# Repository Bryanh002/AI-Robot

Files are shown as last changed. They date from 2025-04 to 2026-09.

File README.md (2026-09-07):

```
███████╗██████╗  ██████╗  ██████╗ ███████╗
██╔════╝██╔══██╗██╔════╝ ██╔═══██╗██╔════╝
█████╗  ██████╔╝██║  ███╗██║   ██║███████╗
██╔══╝  ██╔══██╗██║   ██║██║   ██║╚════██║
███████╗██║  ██║╚██████╔╝╚██████╔╝███████║
╚══════╝╚═╝  ╚═╝ ╚═════╝  ╚═════╝ ╚══════╝
```
### Embodied Reinforcement Gait Optimization System
---

<p align="center">
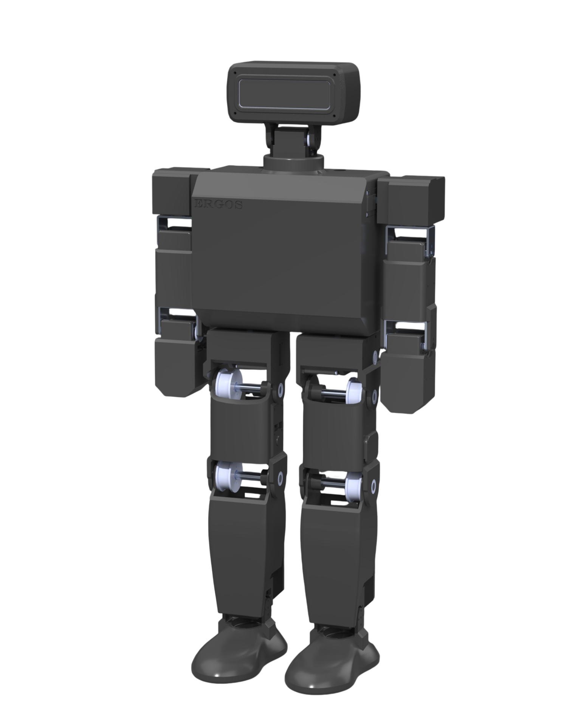
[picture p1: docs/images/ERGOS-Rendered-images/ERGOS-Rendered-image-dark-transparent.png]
  
  <br>
</p>

---

## Project Overview

ERGOS is a low-cost, open-source 20-DOF humanoid platform for dynamic locomotion research. It is a self-contained robot: 3D-printed structure, belt-driven Feetech STS serial servos, a custom motherboard, and a Jetson Orin Nano as the onboard computer.

The long-term goal is stable, adaptive bipedal gait on this hardware. High-level perception, planning, and learned policies run on the Jetson inside a ROS 2 control stack. Low-level servo timing and bus I/O run on an ESP32-S3. Simulation and training use NVIDIA Isaac Sim / Isaac Lab and PyTorch; trained policies are meant to transfer onto the physical robot.

---

## 🗺️ Repository Map

- **Hardware**
  - [`mechanical/`](mechanical/) — SolidWorks CAD (current: ERGOS V1.4), STEP exports, renders, walking tether
  - [`Electrical/`](Electrical/) — Altium motherboard project, schematics, PCB
- **Software**
  - [`software/`](software/) — ESP32 firmware examples now; ROS 2 packages, tools, and simulation wiring as they land
- **Docs**
  - [`docs/`](docs/) — architecture diagram, renders, datasheets, BOM

---

## ERGOS Features

### Mechanical System *(designed — V1.4)*
- Custom 20-DOF humanoid: legs, arms, neck/head, and torso packaging for battery, motherboard, and Jetson
- Belt-driven joints using HTD-3M pulleys (18T driving, 30T driven) for torque amplification at selected axes
- 3D-printed structural housings for low cost and fast iteration
- Modular joint layout so actuators and transmissions can be swapped without redesigning the whole robot
- Safety tether (4040 extrusion frame) for early walking tests

### Electronics & Power *(designed — testing)*
- Custom motherboard with an ESP32-S3 for real-time servo communication
- On-board full-duplex to half-duplex TTL path for two Feetech STS buses at 1 Mbps
- BMI323 IMU on the motherboard; two force-sensing resistors on each foot
- Power from a 3S 8400 mAh LiPo: eFuse-protected distribution to the servo harness, boost to 18 V for the Jetson
- Jetson Orin Nano as the primary compute module; USB from the Jetson powers the PCB logic (ESP32) and carries control
- OAK-D Lite depth camera in the head for later perception work

### Control & Locomotion *(planned)*
- ROS 2 control stack on the Jetson: policy inference, state estimation, and command streaming to the ESP32
- Reinforcement learning for walking, trained in simulation and transferred onto hardware
- Simulation and training in **NVIDIA Isaac Sim / Isaac Lab** with **PyTorch**
- [ServoSim](https://github.com/Bryanh002/ServoSim) research is aimed at getting the best locomotion performance on ERGOS given its limited DOF and serial-bus actuator class

### Environmental Perception *(planned)*
- OAK-D Lite for depth and RGB
- Fusion of vision, IMU, and foot sensing into locomotion and navigation

---

## System Architecture

<p align="center">
  
  <br>
</p>

**Figure 1.** High-level system architecture of the ERGOS humanoid platform. A 3S LiPo feeds the custom motherboard: servo-bus power at battery voltage, and a boost converter to 18 V for the Jetson Orin Nano (18 V leaves more buffer on the Jetson input). The Jetson runs perception, planning, and learned policies in ROS 2, and powers the ESP32 logic rail over USB while streaming commands. The MCU drives two half-duplex Feetech STS buses and reads the on-board IMU and foot FSRs (two per foot). Arms are 4 DOF each; legs 5 DOF; neck 2 DOF. The OAK-D Lite connects to the Jetson over USB 3.0. Diagram source: [`docs/ergos_mermaidchart.txt`](docs/ergos_mermaidchart.txt).

---

## Development Plan

| Phase | Focus | Status |
| :--- | :--- | :--- |
| **1. Hardware platform** | V1.4 CAD, motherboard (designed — testing), harness, assembly, tether | In progress |
| **2. Embedded control** | ESP32 servo firmware, Jetson bring-up, ROS 2 driver | Starting (bus examples exist) |
| **3. Simulation & RL** | Isaac Sim / Isaac Lab, PyTorch locomotion policies | Planned |
| **4. Sim-to-real walking** | Transfer onto ERGOS, tethered then free walking | Planned |
| **5. Perception** | OAK-D in the control loop | Planned |

**Phase 1 — Hardware platform.** Current work. Build the V1.4 mechanical design. The custom motherboard is designed and in testing (servo buses, power distribution, IMU, foot FSRs, Jetson 18 V rail). Assemble the robot and the walking tether.

**Phase 2 — Embedded control.** Firmware on the ESP32-S3 for dual-bus STS command/feedback, then a ROS 2 layer on the Orin Nano that talks to that MCU. Servo ID map, calibration, and a first standing / joint-tracking controller.

**Phase 3 — Simulation and RL.** Model ERGOS in Isaac Sim / Isaac Lab and train walking policies with PyTorch. This is also where ERGOS is used as the hardware test platform for [ServoSim](https://github.com/Bryanh002/ServoSim).

**Phase 4 — Sim-to-real walking.** Run trained policies on the Jetson, first on the tether, then untethered.

**Phase 5 — Perception.** Bring the OAK-D Lite into locomotion and navigation.

---

## Technical Summary

| Item | Choice |
| :--- | :--- |
| **On-robot compute** | NVIDIA Jetson Orin Nano (JetPack, ROS 2) |
| **Real-time MCU** | ESP32-S3 (C/C++, Arduino today) |
| **Actuators** | Feetech STS3250 (14×) and STS3235 (6×), TTL half-duplex @ 1 Mbps |
| **Sensors** | BMI323 IMU, OAK-D Lite, two FSRs per foot |
| **Power** | 3S 8400 mAh LiPo → motherboard eFuse / boost (18 V Jetson) / servo rails; Jetson USB powers PCB logic |
| **Simulation & training** | NVIDIA Isaac Sim / Isaac Lab, PyTorch |
| **Control stack** | ROS 2 on the Jetson, USB/UART to the ESP32 |
| **CAD / PCB** | SolidWorks, Altium Designer |

---

## Getting Started

The robot is still being built. There is not a one-command install yet. Use the folders that actually exist:

1. **Mechanical** — [mechanical/README.md](mechanical/README.md) · CAD in `mechanical/ERGOS_V1.4/`, STEP exports, interactive renders. Full assembly instructions will live there; they are not written yet.
2. **Electrical** — [Electrical/README.md](Electrical/README.md) · Altium project, schematic PDF, motherboard overview.
3. **BOM** — [docs/README.md](docs/README.md) · current parts list. This spreadsheet is out of date and will be rebuilt last.
4. **Software** — [software/README.md](software/README.md) · ESP32 bus examples now. ROS 2, Isaac, and training docs come with Phase 2–3.

**Later (when those phases land):** JetPack / Python environment, simulation setup, training and deployment, and a servo ID / wiring map.

---

## 📜 License

This project is open source and released under the **MIT License**.  
See the [LICENSE](LICENSE) file for more information.

---

## 👤 Project Developer

**Bryan Heddle**  
Mechatronics & AI Systems Engineering Student — *Western University*

---

## 💡 Acknowledgments

Thanks to the open-source robotics community for the tools, documentation, and work this project builds on.

**Project sponsors:**
- **[Thompson Innovation Fund](https://www.eng.uwo.ca/tc/innovation-fund.html)**
- **[WESEF](https://www.eng.uwo.ca/departments-units/finance-stores/undergrads/wesef.html)**
- **[Luxonis](https://www.luxonis.com/)**
- **[GoBilda](https://www.gobilda.com/)**
---

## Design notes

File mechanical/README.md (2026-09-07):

# Mechanical

ERGOS V1.4 is the current mechanical design: a 20-DOF 3D-printed humanoid with belt-driven joints and Feetech STS serial servos.

This page is a map of the CAD, not a full assembly manual. That manual will live here when the build is stable enough to write down.

## What's in this folder

| Path | Contents |
| :--- | :--- |
| [`ERGOS_V1.4/`](ERGOS_V1.4/) | Current robot — parts, assemblies, STEP exports |
| [`ERGOS_Tether_V2/`](ERGOS_Tether_V2/) | Walking-support frame (4040 extrusion, casters) |
| [`ERGOS_Tether_V1/`](ERGOS_Tether_V1/) | Earlier tether |
| [`Renders/`](Renders/) | Interactive 360° viewers and stills |
| [`Prototypes [Legacy]/`](Prototypes%20[Legacy]/) | V1–V1.3 CAD kept for history |

Open **`ERGOS_V1.4/Assemblies/Final_Robot_Assembly.SLDASM`** for the full robot.

## Design snapshot (V1.4)

- **Structure:** printed housings (PLA for most structure; TPU where compliance is needed) with COTS bearings, shafts, and fasteners
- **Actuation:** Feetech STS3250 on the high-load joints (hips, knees, shoulders) and STS3235 on lighter joints (arms, neck)
- **Transmission:** selected joints use HTD-3M belts — 18T pulley on the servo side, 30T on the output — for torque at the expense of speed
- **Packaging:** battery, motherboard, and Jetson Orin Nano in the torso; OAK-D Lite in the head behind the visor
- **Support:** a 4040 tether so early walking tests do not dump the robot on the floor

Datasheets for the servos are in [`docs/Datasheets/`](../docs/Datasheets/).

## CAD layout (V1.4)

```
ERGOS_V1.4/
  Assemblies/     top-level and subsystem assemblies
  Parts/          printed parts + COTS models used in those assemblies
  Exports/        STEP for print / fab / sharing
```

### Top-level assemblies

| Assembly | Role |
| :--- | :--- |
| `Final_Robot_Assembly.SLDASM` | Full robot |
| `Chassis_Assembly.SLDASM` | Torso, battery, PCB tray, Jetson |
| `Robot_Head_Assembly.SLDASM` | Head, visor, OAK-D Lite, neck |
| `Shoulder_Assembly_Left/Right.SLDASM` | Shoulders |
| `Upper_Arm_Assembly.SLDASM` / `Lower_Arm_Assembly.SLDASM` | Arms |
| `Hip_Housing_Assembly_Left/Right.SLDASM` | Hips |
| `Thigh_Housing_Assembly_Left/Right.SLDASM` | Thighs |
| `Shin_Left/Right_Assembly.SLDASM` | Shins |
| `Ankle_Assembly_Left/Right.SLDASM` | Ankles / feet |
| `Jetson_Orin_Nano_Assembly.SLDASM` | Orin Nano + mounter |
| `ROBOT_MOTHERBOARD.SLDASM` | Motherboard STEP in CAD |
| `Oak-d-lite.SLDASM` | Camera |

Left/right copies of housings are explicit parts (not a single mirrored configuration), so print the matching file for each side.

### Joints and hardware that show up often

- **Pulleys:** `HTD3M-18T-8mm`, `HTD3M-30T-10mm`
- **Shafts:** 8 mm aluminum, several cut lengths (about 30 mm and 68 mm in CAD)
- **Bearings:** MR148 and 6801-2RS at different joints
- **Servo interface:** 25T spline horns (`Servo-horn-gear`, `Servo-horn-smooth`) and GoBilda 8 mm round servo shafts where the belt stage needs a round shaft
- **Shims:** 8×11×0.25 mm washers

A print list, belt lengths, and fastener callouts will go here when the BOM is rebuilt. Do not treat [`docs/README.md`](../docs/README.md) as exact quantities until that happens.

## Tether

`ERGOS_Tether_V2/` is a rolling 4040 frame with casters so the robot can walk with catch support. Use this for Phase 4 (sim-to-real walking) before untethered tests.

## Renders

Current SolidWorks visualizer export. Open [`Renders/ERGOS-Interactive/Data/index.html`](Renders/ERGOS-Interactive/Data/index.html) locally and drag to rotate.

<p align="center">
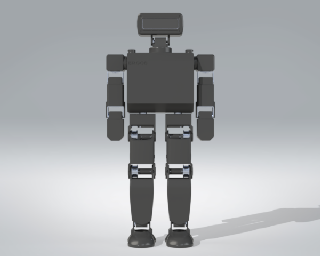
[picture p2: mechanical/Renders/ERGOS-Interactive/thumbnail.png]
ERGOS interactive CAD turntable
  
</p>

Still images used on the GitHub README: [`docs/images/ERGOS-Rendered-images/`](../docs/images/ERGOS-Rendered-images/).

## Still to document

- Exploded assembly order (this is the hard one — it will be its own section)
- Print settings, material per part, and support strategy
- Belt routing and tension
- Wiring paths through the limbs into the torso harness
- Mass properties / COM from the SolidWorks assembly

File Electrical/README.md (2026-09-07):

# Electrical

Custom motherboard for ERGOS: servo-bus I/O, power distribution, IMU, foot FSRs, and an 18 V rail for the Jetson Orin Nano.

This is an overview of the current Altium project (V3), not a full bring-up or assembly guide. Schematics and layout are the source of truth.

## What's in this folder

| Path | Contents |
| :--- | :--- |
| [`PCB_Project/ROBOT_PCB_PROJECT.PrjPcb`](PCB_Project/ROBOT_PCB_PROJECT.PrjPcb) | Altium project |
| [`PCB_Project/ROBOT_MOTHERBOARD.PcbDoc`](PCB_Project/ROBOT_MOTHERBOARD.PcbDoc) | Board layout |
| [`PCB_Project/Schematics/`](PCB_Project/Schematics/) | Four schematic sheets + PDF export |
| [`PCB_Project/PCB_BOM.xlsx`](PCB_Project/PCB_BOM.xlsx) | Motherboard component BOM |
| [`images/history/`](images/history/) | V1–V3 board renders |

The robot-level parts list (battery, Jetson, camera, wire, etc.) lives in [`docs/README.md`](../docs/README.md) and will be rebuilt later.

## Board role

The motherboard sits in the torso on the PCB tray. It does four jobs:

1. **Take 3S LiPo power** (nominal 11.1 V) in through an XT90, protect it, and split it.
2. **Feed the servo harness** at battery voltage for the Feetech STS daisy chains.
3. **Boost to 18 V** and send it out a barrel jack to the Jetson Orin Nano Dev Kit. 18 V is used instead of 19 V to leave more buffer on the Jetson input.
4. **Talk to the servos** from an ESP32-S3 over two half-duplex TTL buses, and read the on-board IMU plus foot FSRs.

The Jetson is the high-level computer (ROS 2, camera, policies). The ESP32 is the real-time bus master. They connect over USB: the Jetson both talks to the MCU and **powers the logic side of the PCB** (ESP32 and 3.3 V rail). Servo/power electronics stay on the battery + eFuse path.

## Schematic sheets

| Sheet | What it covers |
| :--- | :--- |
| `MCU_IMU.SchDoc` | ESP32-S3-MINI-1-N8, 3.3 V LDO, USB, boot/reset, BMI323 IMU |
| `UART_LOGIC.SchDoc` | Full-duplex MCU UART → half-duplex STS bus transceivers / buffers (two buses) |
| `Battery_power.SchDoc` | XT90 input, TVS, eFuse, servo-rail distribution and connectors |
| `Jetson_power.SchDoc` | TPS43060 boost 11.1 V → 18 V, barrel-jack output |

A combined PDF is in [`PCB_Project/Schematics/Schematics_PDF.PDF`](PCB_Project/Schematics/Schematics_PDF.PDF).

## Power tree

```
3S LiPo 8400 mAh  (11.1 V nominal)
        │
        ▼
   XT90  →  TVS  →  TPS25985 eFuse
                    │
        ┌───────────┴───────────┐
        ▼                       ▼
  Servo harness (11.1 V)   TPS43060 boost → 18 V barrel jack → Jetson
        │                                              │
        ├─ Neck                                        └─ USB 5V → PCB logic (ESP32)
        ├─ Right arm / right leg
        └─ Left arm / left leg
```

Servo power is not a second regulated 12 V rail; the STS servos run from the 3S pack through the eFuse and harness. The Jetson is fed 18 V on its barrel jack; it then powers the ESP32 side of this board over USB.

There are also keyed fuse holders on the board (`F2`–`F5`) for downstream rails.

## Communication

Two independent **1 Mbps half-duplex Feetech SCS/STS** buses. The MCU UARTs are full duplex; on-board logic (level shifters, inverters, 3-state buffers) turns each into a single-wire TTL servo bus with a direction pin.

Bus split:

- **Bus 1** — neck, right arm, right leg
- **Bus 2** — left arm, left leg

The Jetson talks to the ESP32 over USB (CDC UART) and supplies logic power on that same link. The OAK-D Lite is USB 3.0 into the Jetson, not into this board.

On-board sensors:

- **BMI323** IMU on I²C to the ESP32
- **Foot FSRs** — two per foot, on MCU ADC

## BOM

Motherboard components: [`PCB_Project/PCB_BOM.xlsx`](PCB_Project/PCB_BOM.xlsx)

Robot-level BOM (battery, compute, mechanical, wire): [`docs/README.md`](../docs/README.md) — out of date, rebuild comes last.

## Mechanical fit

CAD for the board is `mechanical/ERGOS_V1.4/Assemblies/ROBOT_MOTHERBOARD.SLDASM` (and the matching `.step`). It mounts in `PCB-tray` in the chassis, with the Jetson on its own mounter above/beside it.

## Firmware on this board

Bring-up sketches that toggle the half-duplex direction pin and talk to an STS servo are in [`software/src/Arduino/Examples/`](../software/README.md). They are not the production firmware.

Servo comms use a project-specific Feetech STS library: **[ERGOS_FTServo_Arduino](https://github.com/Bryanh002/ERGOS_FTServo_Arduino)** — not the stock Feetech `SCServo` package. Same note is in the [software](../software/README.md) docs.

## Board history

Descriptions of what changed between revisions will go here later.

### V1

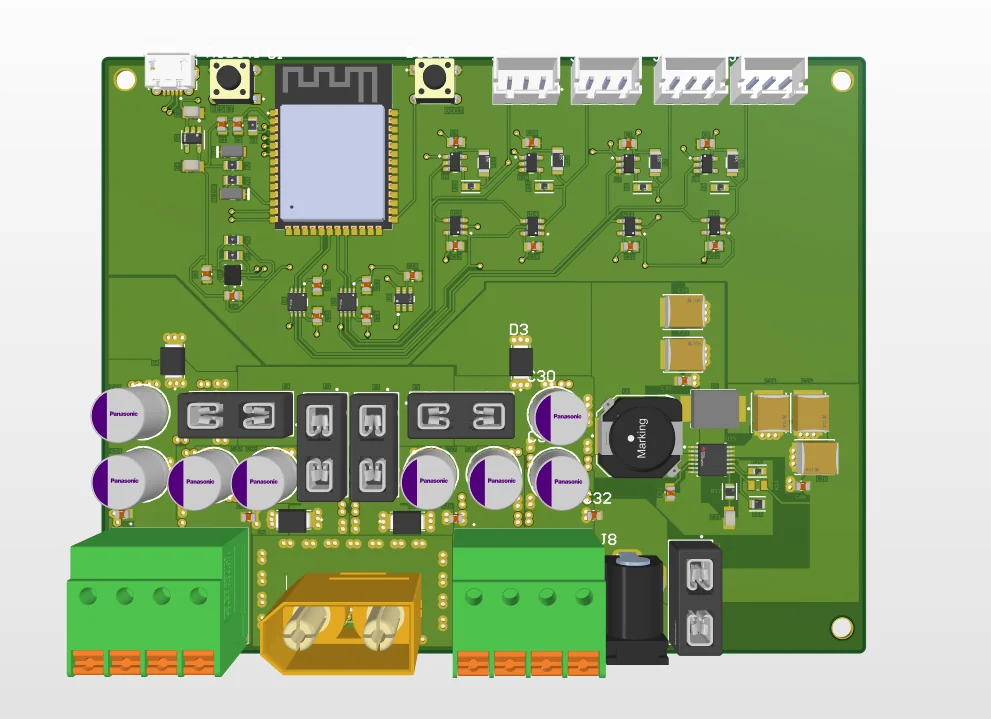
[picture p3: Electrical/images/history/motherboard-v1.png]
ERGOS motherboard V1


### V2

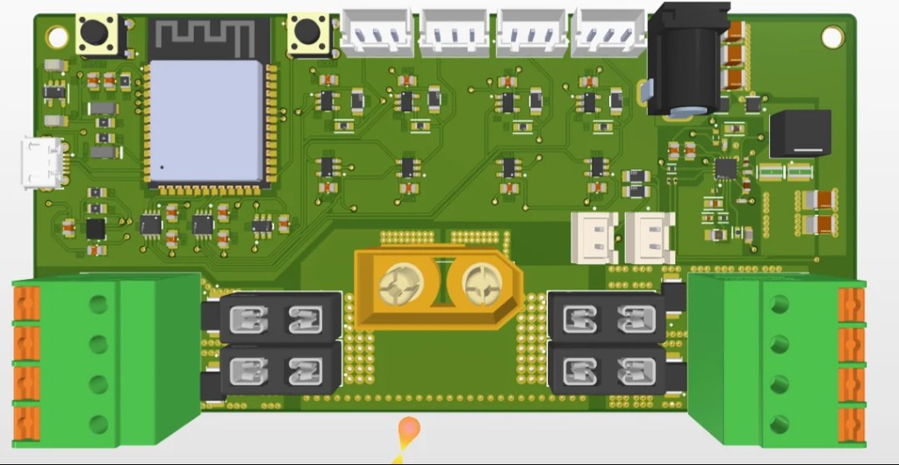
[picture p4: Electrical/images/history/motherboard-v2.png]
ERGOS motherboard V2


### V3 (current)

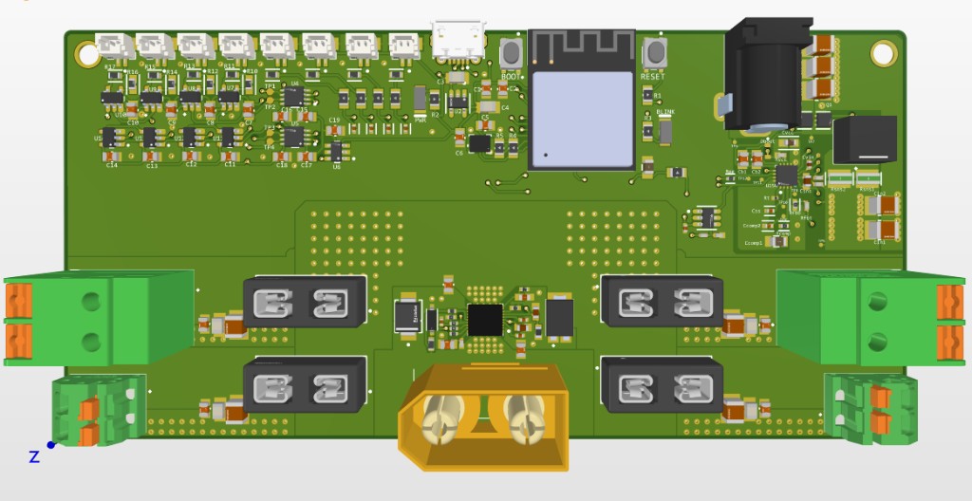
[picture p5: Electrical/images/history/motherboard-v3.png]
ERGOS motherboard V3


## Still to document

- Connector pinouts and harness drawing
- Measured current budgets (idle / walking)
- Programming / boot-button procedure
- First-power checklist

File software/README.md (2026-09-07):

# Software

Software for ERGOS is the stack that will run **on the robot** and the tools used to **train models for it**. That work is still early. This folder currently holds ESP32 bus bring-up sketches only.

ROS 2 packages, Isaac assets, and training code will land here (or be linked from here) as Phase 2–3 start. Until then, treat this page as the intended architecture.

## Intended stack

| Layer | Where it runs | Tools |
| :--- | :--- | :--- |
| Policy training | Workstation / lab GPU | **NVIDIA Isaac Sim**, **Isaac Lab**, **PyTorch** |
| Onboard autonomy | Jetson Orin Nano | **ROS 2**, JetPack, Python / C++ |
| Real-time actuation | ESP32-S3 on the motherboard | C/C++ (Arduino today) |
| Perception | Jetson + OAK-D Lite | DepthAI / ROS 2 camera pipeline *(planned)* |

Flow, once it exists:

1. Train locomotion policies in Isaac Sim / Isaac Lab with PyTorch.
2. Run the policy on the Jetson inside ROS 2 (state in, joint commands out).
3. The Jetson streams commands to the ESP32 over USB/UART and powers the PCB logic rail on that same USB link.
4. The ESP32 is the Feetech STS bus master (two 1 Mbps half-duplex buses) and reads the BMI323 IMU and foot FSRs.

The root README's development plan is the schedule: hardware and MCU bring-up first, then ROS 2, then simulation/RL, then sim-to-real walking.

## ServoSim (separate project)

ERGOS is also the **hardware test platform** for [ServoSim](https://github.com/Bryanh002/ServoSim).

ServoSim is not a substitute for the ERGOS software stack. It is an Isaac Lab extension for learned actuator models and domain randomization on position-controlled serial-bus servos (the same Feetech STS class used here). The research is aimed at getting the best locomotion performance on ERGOS given its limited DOF and actuator class.

- ERGOS software (this repo): robot firmware, ROS 2, the ERGOS sim/control bring-up
- [ServoSim](https://github.com/Bryanh002/ServoSim): servo modeling / DR research that uses ERGOS as the real-world target

## What's in this folder today

```
software/src/Arduino/Examples/
  Full-to-Half_Duplex_Test/   direction-pin toggle on the UART transceiver
  STS_Servo_Ping/             ping / write-position smoke test
  STS_Servo_WritePos/         read position, command two setpoints
```

These sketches talk to a single STS servo on `Serial1` at **1 Mbps**, using **[ERGOS_FTServo_Arduino](https://github.com/Bryanh002/ERGOS_FTServo_Arduino)** — a project-specific Feetech STS library, not the stock `SCServo` package.

| Signal | GPIO (current examples) |
| :--- | :--- |
| UART TX / RX | 12 / 11 (`Serial1`) |
| Bus direction | 4 (HIGH = transmit, LOW = receive) |
| LED | 8 |
| Debug USB serial | 115200 baud |

They match the motherboard's half-duplex direction control. They are not a multi-bus controller, not ROS 2, and not safe to run as a standing robot.

## Planned in this repo (not written yet)

- Production ESP32 firmware: dual bus, ID map, feedback at control rate
- ROS 2 package(s) on the Jetson: MCU bridge, joint states, command interface
- URDF / Isaac description of ERGOS that tracks V1.4 CAD
- Launch files, calibration, and a first standing controller
- Training and deployment notes once the sim model is stable

## Related hardware docs

- [Electrical](../Electrical/README.md) — buses, IMU, FSRs, Jetson 18 V rail
- [Mechanical](../mechanical/README.md) — V1.4 CAD the sim model needs to match
- Servo datasheets: [`docs/Datasheets/`](../docs/Datasheets/)

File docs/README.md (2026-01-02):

# Bill of Materials (BOM)

This folder contains the full Bill of Materials for the project.  
For the original spreadsheet, which contains more detailed descriptions for each part, see [Robot_BOM.xlsx](./Robot_BOM.xlsx).

---

## ⚙️ Mechanical
| Part | Description | Qty | Unit Cost | Total (w/ Tax) |
| :--- | :--- | :---: | :--- | :--- |
| **STS3250 50kg-cm TTL Dual-shaft** | High-torque smart servo for hip, knee, and shoulder joints. | 14 | $65.81 | $1,041.11 |
| **STS3235 30kg-cm TTL Dual-shaft** | Medium-torque smart servo for arm and neck joints. | 6 | $57.86 | $392.29 |
| **8mm Round Servo Shaft** | Shaft adapter for belt-driven joint transmission (15% Discount from GoBilda Applied). | 6 | $9.99 | $67.73 |
| **HTD 3M 18T Timing Pulley** | Driving pulley in belt reduction stage. | 8 | $3.02 | $27.30 |
| **HTD 3M 30T Timing Pulley** | Driven pulley for torque amplification. | 4 | $6.79 | $30.69 |
| **Screw Kit (M1.6–M3)** | Assorted fasteners for structural assembly. | 1 | $11.80 | $13.33 |
| **8mm ID / 11mm OD Washers** | Shim washers to control axial play (15% Discount from GoBilda Applied). | 3 | $2.69 | $9.12 |
| **MR148ZZ Bearings** | Radial bearings for joint rotation. | 1 | $18.95 | $21.41 |
| **Spring Pins** | Mechanical locking pins for shafts. | 1 | $10.19 | $11.51 |
| **TPU Filament** | Flexible filament for compliant parts. | 1 | $29.99 | $33.89 |
| **PLA Filament** | Rigid filament for structural 3D prints. | 3 | $25.99 | $88.11 |
| **Loctite 638** | High-strength retaining compound. | 1 | $24.00 | $27.12 |
| **Mechanical Subtotal** | | | | **$1,763.61** |

---

## ⚡ Electrical
| Part | Description | Qty | Unit Cost | Total (w/ Tax) |
| :--- | :--- | :---: | :--- | :--- |
| **3S LiPo 8400mAh** | Main power source for servos and compute. | 1 | $99.99 | $112.99 |
| **Custom PCB (JLCPCB)** | Power distribution and communication board. | 1 | $283.00 | $319.79 |
| **PCB SMD and THT components** | all components required for PCB. | 1 | $85.00 | $96.05 |
| **Male to Male DC Power Cable** | A power cable for the Jetson that connects to the PCB. | 1 | $10.39 | $11.74 |
| **14 Gauge Wire** | 14 Gauge wire for power distribution | 1 | $22.07 | $24.94 |
| **22 Gauge Wire** | 22 Gauge wire for branching power and signal distribution | 1 | $15.89 | $17.96 |
| **Electrical Subtotal** | | | | **$583.47** |

---

## 🧠 Software & Computing
| Part | Description | Qty | Unit Cost | Total (w/ Tax) |
| :--- | :--- | :---: | :--- | :--- |
| **Jetson Orin Nano** | Main compute for perception, control, and RL. | 1 | $344.95 | $389.79 |
| **OAK-D Lite** | Stereo depth camera for perception (30% Discount from Luxonis applied). | 1 | $162.00 | $183.06 |
| **KingSpec 256GB NVMe SSD** | Storage for models, logs, and datasets. | 1 | $32.99 | $37.28 |
| **Computing Subtotal** | | | | **$610.13** |

---

## 💰 Grand Total
| Category | Total (w/ Tax) |
| :--- | ---: |
| Mechanical | $1,763.61 |
| Electrical | $583.47 |
| Software & Computing | $610.13 |
| **Grand Total** | **$2,957.21** |

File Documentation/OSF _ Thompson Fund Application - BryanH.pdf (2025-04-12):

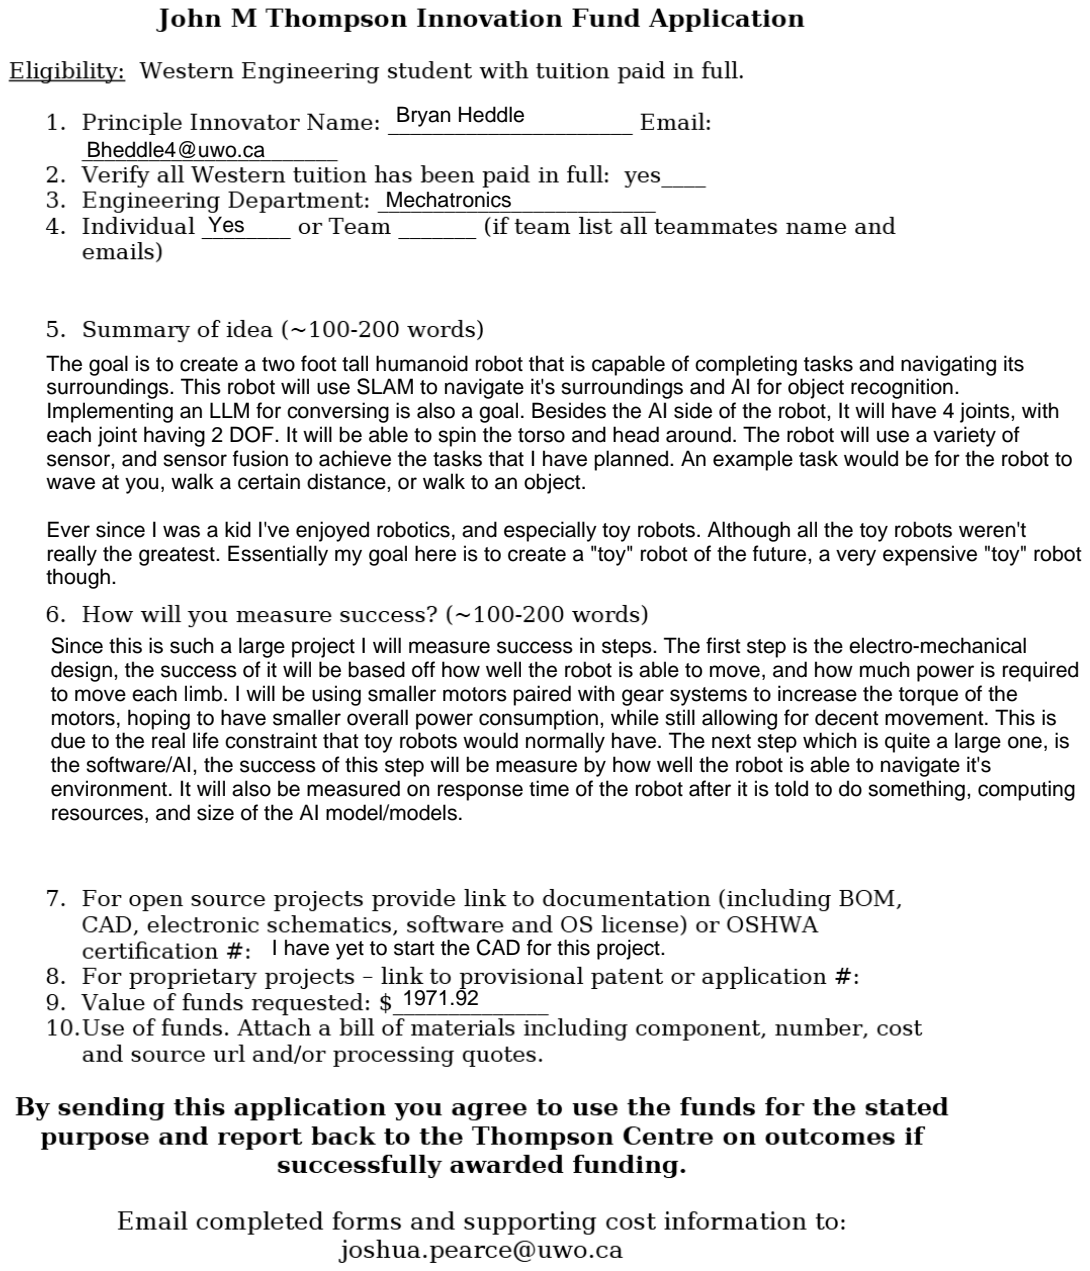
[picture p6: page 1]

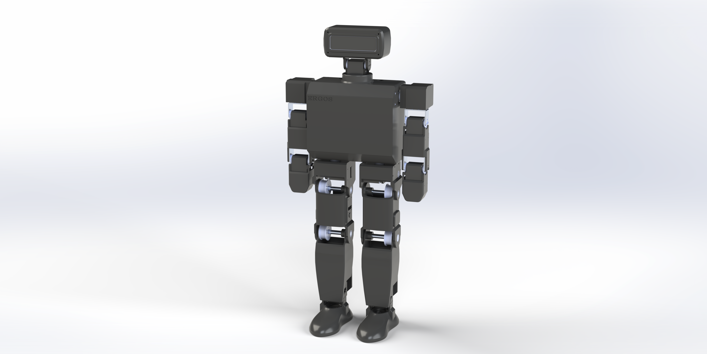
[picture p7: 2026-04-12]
docs/images/ERGOS-Rendered-images/ERGOS-Rendered-image.png

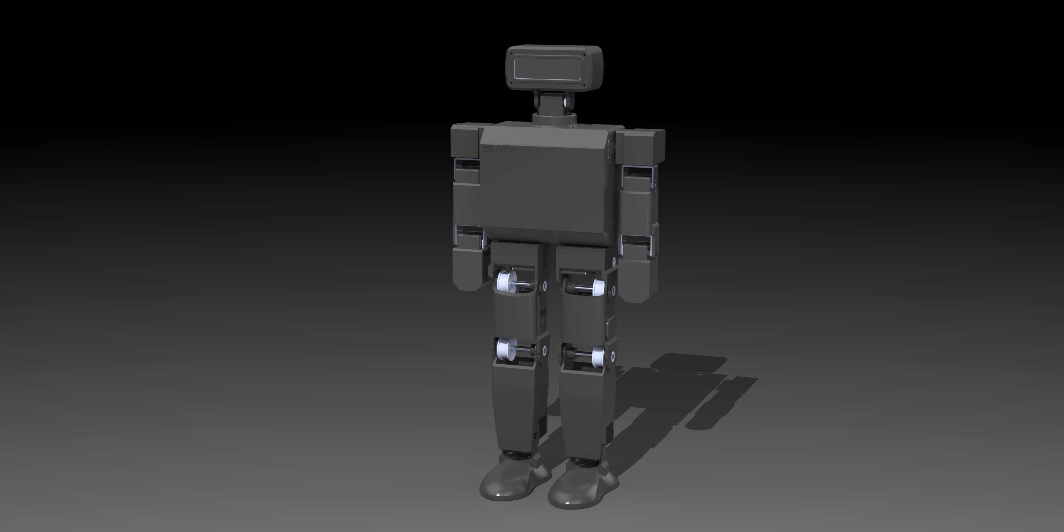
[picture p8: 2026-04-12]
docs/images/ERGOS-Rendered-images/ERGOS-Rendered-image-dark.png

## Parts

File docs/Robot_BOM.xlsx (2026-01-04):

Part | Product Link | Description | Quantity | Cost | Total Cost + Tax | Final Cost
MECHANICAL |  |  |  |  |  | $2876.40
STS3250 50kg-cm TTL Dual-shaft | https://www.feetechrc.com/en/562636.html | High-torque smart servo used for the hip, knee, and shoulder joints to handle the primary load-bearing and dynamic movement required for humanoid locomotion. | 14 | $65.81 | $1041.11
STS3235 30kg-cm TTL Dual-shaft | https://www.feetechrc.com/en/12v-30kg-metal-shell-metal-tooth-iron-core-motor-magnetic-coding-double-shaft-ttl-series-steering-gear.html | Medium-torque smart servo used for arm and neck joints where lower torque is sufficient but precise control is still required for coordinated movement. | 6 | $57.86 | $392.29
8mm Round Servo Shaft | https://www.gobilda.com/8mm-round-servo-shaft-25-tooth-spline-36mm-length/ | Custom shafts used to transfer motion between servo outputs and pulley assemblies, enabling reliable and backlash-free mechanical transmission. | 6 | $9.99 | $67.73
HTD 3M 18T Timing pulley | https://www.aliexpress.com/item/1005007456973949.html | Serves as the driving pulley in the belt transmission system, translating servo rotation. | 8 | $3.02 | $27.30
HTD 3M 30T Timing Pulley | https://www.aliexpress.com/item/1005009686443539.html | Acts as the driven pulley in the gear reduction setup, increasing torque at each joint. | 4 | $6.79 | $30.69
8mm ID 11 mm OD Washers | https://www.gobilda.com/2807-series-stainless-steel-shim-8mm-id-x-11mm-od-0-25mm-thickness-12-pack/ | Used to reduce axial friction and prevent rubbing between rotating parts and stationary brackets. | 1 | $2.69 | $3.04
MR95ZZ Bearings | https://www.amazon.ca/uxcell-Bearings-8x12x3-5mm-Miniature-Precision/dp/B0CM6G9ZKZ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 | Smaller bearings used in compact joint housings where load and speed requirements are moderate. | 1 | $16.29 | $18.41
PLA | https://www.amazon.ca/ELEGOO-Filament-Dimensional-Accuracy-Cardboard/dp/B0C8J1JZMT?s=industrial | 3D printing material used for lightweight housings and custom mounts throughout the robot prototype to allow iterative design, it's likely I'll need lots of PLA due to continous prints, and like mentioned, fixes. | 2 | $44.99 | $101.68
Loctite 638 | https://www.amazon.ca/Loctite-21448-Strength-Retaining-Compound/dp/B000O01EV0 | High-strength retaining compound for securing shafts, pulleys, and bearings, preventing slippage under dynamic loads. | 1 | $24 | $27.12
ELECTRICAL |  |  |  |  | 0
3s lipo 8400mah 11.1v 120c | https://www.amazon.ca/DXF-Battery-Hardcase-Airplane-Helicopter/dp/B09TDFVWHS | Primary power source for servos, Jetson Orin Nano, and sensors; provides sufficient current delivery for high-demand movements. | 1 | $99.99 | $112.99
PCB | JLCPCB | Central power and communication hub distributing regulated voltage and serial signals between servos, Jetson, and sensors. | 1 | $284.00 | $320.92
PCB components | Digikey (https://www.digikey.ca/short/0zvnp1rd) | all components required for PCB | 1 | $109 | $123.17
14 AWG Red and Black Wire |  |  |  |  | 0
SOFTWARE
Jetson Orin Nano | https://www.amazon.ca/NVIDIA-Jetson-Orin-Nano-Developer/dp/B0BZJTQ5YP | Main onboard computer handling perception, reinforcement learning, and motion planning in real time. | 1 | $344.95 | $389.79
OAK-D Lite | https://shop.luxonis.com/products/oak-d-lite-1 | Provides depth and RGB vision for environmental awareness, obstacle detection, and balance correction. Received 30% discount from Luxonis reducing the price from $209.8 to $147 CAD. | 1 | $146.84 | $165.93
Patriot P320 128GB SSD | https://www.amazon.ca/dp/B0D4RD18YV?ref=ppx_yo2ov_dt_b_fed_asin_title&th=1 | High-speed storage for AI models, video frames, and system data during real-time inference and logging. | 1 | $47.99 | $54.23

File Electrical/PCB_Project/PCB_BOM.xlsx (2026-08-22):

Line # | Name | Description | Designator | Quantity | Manufacturer 1 | Manufacturer Part Number 1
 | SML-LX1206IC-TR | LED Red, 65 mW, -40 to 85 degC, 2-Pin SMD, RoHS, Tape and Reel | BLINK, PWR | 2 | Lumex | SML-LX1206IC-TR
 | PTS810SJM250SMTRLFS (PTS810SJM250SMTR LFS) | SWITCH TACTILE SPST-NO 0.05A 16V | Boot1, Reset1 | 2 | C&K Components | PTS810SJM250SMTRLFS
 | CC0805KRX7R9BB104 | CAP CER 0.1UF 50V X7R 0805 | C1, C2, C5, C6, C7, C8, C9, C10, C11, C12, C13, C14, C15, C16, C17, C18, C19, C22, C25, C28, C31, C32, Cboot1, Cboot2 | 24 | Yageo Group | CC0805KRX7R9BB104
 | C0805C105K5RACTU |  | C3, C4, C21, C24, C27, C30 | 6 | Yageo Group | C0805C105K5RACTU
 | CL32A106KBJNNNE | Cap Ceramic 10uF 50V X5R ±10% SMD 1210 +85°C Embossed T/R | C20, C23, C26, C29, Cin1, Cin2 | 6 | Samsung Electro-Mechanics | CL32A106KBJNNNE
 | CC0805KKX7R9BB225 | CAP CER 2.2UF 50V X7R 0805 | C33, C36 | 2 | Yageo Group | CC0805KKX7R9BB225
 | C1608C0G1E472J080AA | Multilayer Ceramic Capacitors 4.7nF ±5% 25V C0G SMD 0603 | C34 | 1 | TDK | C1608C0G1E472J080AA
 | GRM1885C1H101JA01D | SMD Capacitor C0G(EIA) with Capacitance: 100pF Tol. 5%. Rated Voltage: 50Vdc | C35, C39, Csns | 3
 | GRM155R71H104KE14D | CAP CER 0.1UF 50V X7R 0402 | C37, C38, C40, C41, C42, C43, C44, C45, Css | 9 | Murata Electronics | GRM155R71H104KE14D
 | CGA4C2C0G1H822J060AA | Cap Ceramic 8.2nF 50V C0G 5% Pad SMD 0805 +125°C Automotive T/R | CADC, Ccomp1 | 2 | TDK | CGA4C2C0G1H822J060AA | 2
 | GRM1555C1H391JA01J | Chip Multilayer Ceramic Capacitors for General Purpose, 0402, 390pF, C0G, 30ppm/°C, 5%, 50V | Ccomp2 | 1 | Murata | GRM1555C1H391JA01J
 | CL32B106KBJNNWE | Cap Ceramic 10uF 50V X7R ±10% SMD 1210 +125°C Embossed T/R | Cout1, Cout2, Cout3 | 3 | Samsung Electro-Mechanics | CL32B106KBJNNWE
 | BZT52C4V7-7-F (BZT52C4V7-TP) | No Description Available | CR1 | 1
 | GRM188R61C106MA73D | Chip Multilayer Ceramic Capacitors for General Purpose, 0603, 10uF, X5R, 15%, 20%, 16V | Cvcc | 1 | Murata | GRM188R61C106MA73D
 | GRM155R71C104KA88D | SMD Capacitor X7R(EIA) with Capacitance: 0.10uF Tol. 10%. Rated Voltage: 16Vdc | Cvin | 1
 | SMBJ12A | TVS DIODE 12V 19.9V DO214AA | D1 | 1 | Littelfuse | SMBJ12A
 | PDS1040-13 (PDS1040Q-13) | DIODE SCHOTTKY 40V 10A POWERDI5 | D2 | 1 | Diodes Inc. | PDS1040-13
 | XBS053V15R-G | Diode Schottky 20V 500mA Surface Mount SOD-523 | Dboot | 1
 | 3568 |  | F2, F3, F4, F5 | 4 | Keystone | 3568
 | BM02B-SRSS-TBT(LF)(SN) | CONN WIRE HDR 2POS 1MM STSMD | J1, J2, J3, J4, J11, J12, J13, J14 | 8 | JST | BM02B-SRSS-TBT(LF)(SN)
 | XT90PW-M | Socket; DC supply; XT90; male; PIN: 2; on PCBs; THT; Colour: yellow | J5 | 1
 | 1017503 |  | J6, J8 | 2
 | 1862042 |  | J7, J9 | 2
 | KLDX-0202-B | 3 Conductor Power Jack, 2 break 2 aux contacts | J10 | 1 | Kycon | KLDX-0202-B
 | XAL6060-472MEB | Power inductor, shielded, 20% tol, SMT, RoHS, halogen-f | L1 | 1
 | CSD17571Q2 | MOSFET N-CH 30V 22A 6SON | Q1, Q2 | 2 | Texas Instruments | CSD17571Q2
 | CRCW08054K70FKEA | RES Thick Film, 4.7kΩ, 1%, 0.125W, 100ppm/°C, 0805 | R1, R2, R3, R4, R5, R28, R29, R30, R31, RADC | 10 | Vishay | CRCW08054K70FKEA
 | RC0603FR-0710KL | RES 10K OHM 1% 1/10W 0603 | R6, R7, R8, R9, R11, R13, R15, R17, R27 | 9 | Yageo Group | RC0603FR-0710KL
 | RMCF0603FG47R0 | 47Ω ±1% 0.1W 0603 Thick Film Chip Resistor AEC-Q200 compliant | R10, R12, R14, R16 | 4 | Stackpole Electronics | RMCF0603FG47R0
 | CRCW040210R0FKED |  | R18, Risns-, Risns+ | 3 | Vishay | CRCW040210R0FKED
 | CRCW040210K0FKEDC | RES 10K OHM 1% 1/16W 0402 | R19, R24 | 2 | Vishay | CRCW040210K0FKEDC
 | CRCW0402100KFKED | RES Thick Film, 100kΩ, 1%, 0.063W, 100ppm/°C, 0402 | R20, Rpg | 2 | Vishay Dale | CRCW0402100KFKED
 | RT0402BRD0748K7L | RES SMD 48.7K OHM 0.1% 1/16W | R21 | 1 | Yageo Group | RT0402BRD0748K7L
 | RC0402FR-07499RL | RES Thick Film, 499Ω, 1%, 0.063W, 100ppm/°C, 0402 | R22 | 1 | Yageo Group | RC0402FR-07499RL
 | ERA3AEB102V | Resistor, SMD 1 kOhm 0603 0.1 % | R23 | 1
 | CRCW04021M00FKED | 63mW Thick Film Resistors 75V ±1% ±100ppm/℃ 1MΩ 0402 Chip Resistor - Surface Mount ROHS | R25 | 1 | Vishay | CRCW04021M00FKED
 | CRCW0402121KFKED | RES Thick Film, 121kΩ, 1%, 0.063W, 100ppm/°C, 0402 | R26 | 1 | Vishay | CRCW0402121KFKED
 | CRCW0402475KFKED |  | R32 | 1 | Vishay | CRCW0402475KFKED
 | CRCW040210K0FKEDHP |  | R33 | 1 | Vishay | CRCW040210K0FKEDHP
 | CRCW04025K36FKED | RES Thick Film, 5.36kΩ, 1%, 0.063W, 100ppm/°C, 0402 | Rcomp | 1 | Yageo Group | RC0402FR-075K36L
 | CRCW040211K0FKED | RES Thick Film, 11kΩ, 1%, 0.063W, 100ppm/°C, 0402 | Rfbb | 1 | Vishay | CRCW040211K0FKED
 | CRCW0402150KFKED |  | Rfbt | 1 | Vishay | CRCW0402150KFKED
 | PRL1632-R010-F-T1 | 10 mOhms ±1% 1W Chip Resistor Wide 0612 (1632 Metric), Current Sense Thin Film | Rsns1, Rsns2 | 2 | Susumu | PRL1632-R010-F-T1
 | RC0201FR-07105KL | 105 kOhms Â±1% 0.05W, 1/20W Chip Resistor 0201 (0603 Metric) Moisture Resistant Thick Film | Rt | 1
 | CRCW04022R00FKED |  | Rvcc | 1 | Vishay | CRCW04022R00FKED
 | ESP32-S3-MINI-1-N8 |  | U1 | 1
 | AP2112K-3.3TRG1 | IC REG LINEAR 3.3V 600MA SOT25 | U2 | 1 | Diodes Inc. | AP2112K-3.3TRG1
 | BMI323 | No Description Available | U3 | 1
 | SN74LVC2T45DCTR | 2-Bit Dual Supply Transceiver with Configurable Voltage-Level Shifting and 3-State Outputs 8-SSOP -40 to 85 | U4, U5 | 2
 | SN74LVC2G04DBVRG4 | IC INVERTER 2CH 2-INP SOT23-6 | U6 | 1 | Texas Instruments | SN74LVC2G04DBVRG4
 | SN74AHCT1G125DBVT | Single 4.5-V to 5.5-V buffer with TTL-compatible CMOS inputs and 3-state outputs | U7, U8, U9, U10, U11, U12, U13, U14 | 8
 | TPS43060RTER | IC REG CTRLR BOOST 16WQFN | U15 | 1 | Texas Instruments | TPS43060RTER
 | TPS259851RQPR | 4.5-V to 16-V, 0.59-mÎ©, 80-A stackable compact eFuse with accurate and fast current monitor 26-VQFN-HR -40 to 125 | U16 | 1
 | TPS3700DDCR | IC COMP WINDOW W/REF 6SOT | U17 | 1 | Texas Instruments | TPS3700DDCR
 | 105017-0001 | Micro-USB B Receptacle, Right Angle, Bottom Mount, Surface Mount, with Solder Tabs, -30 to 85 degC, 5-Pin USB, RoHS, Tape and Reel | VIN | 1 | Molex | 105017-0001

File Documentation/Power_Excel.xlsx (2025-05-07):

Component | Idle Current | Running Current | Stall Current | Voltage | Quantity | Battery Specs
RDS5160 Servo | 60 mA | 500 mA | 5 A | 7.4V | 8 | 14.8V
DS3218MG MS24 Servo | 5-10 mA | 120-160 mA | 1.2-2.0 A | 5V | 7 | 5000mAh
Jetson Orin Nano (25W Mode) | N/A | 1.69~2.08 A | N/A | 14.8V~12V | 1 | 500A Max Draw
Gemini 335 | N/A | 460~600 mA | N/A | 5V | 1
ReSpeaker Mic Array | N/A | 170~180 mA | N/A | 5V | 1

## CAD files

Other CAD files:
mechanical/ERGOS_Tether_V2/Tether_V2.SLDASM
mechanical/ERGOS_V1.4/Assemblies/Final_Robot_Assembly.SLDASM
mechanical/ERGOS_V1.4/Assemblies/Upper_Arm_Assembly.SLDASM
mechanical/ERGOS_V1.4/Assemblies/Lower_Arm_Assembly.SLDASM
mechanical/ERGOS_V1.4/Assemblies/Jetson_Orin_Nano_Assembly.SLDASM
mechanical/ERGOS_V1.4/Assemblies/Robot_Head_Assembly.SLDASM
mechanical/ERGOS_V1.4/Assemblies/Shoulder_Assembly_Left.SLDASM
mechanical/ERGOS_V1.4/Assemblies/Chassis_Assembly.SLDASM
mechanical/ERGOS_V1.4/Assemblies/Hip_Housing_Assembly_Left.SLDASM
mechanical/ERGOS_V1.4/Assemblies/Shin_Left_Assembly.SLDASM
mechanical/ERGOS_V1.4/Assemblies/Thigh_Housing_Assembly_Right.SLDASM
mechanical/ERGOS_V1.4/Assemblies/Shoulder_Assembly_Right.SLDASM
mechanical/ERGOS_V1.4/Assemblies/Thigh_Housing_Assembly_Left.SLDASM
mechanical/ERGOS_V1.4/Assemblies/Shin_Right_Assembly.SLDASM
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

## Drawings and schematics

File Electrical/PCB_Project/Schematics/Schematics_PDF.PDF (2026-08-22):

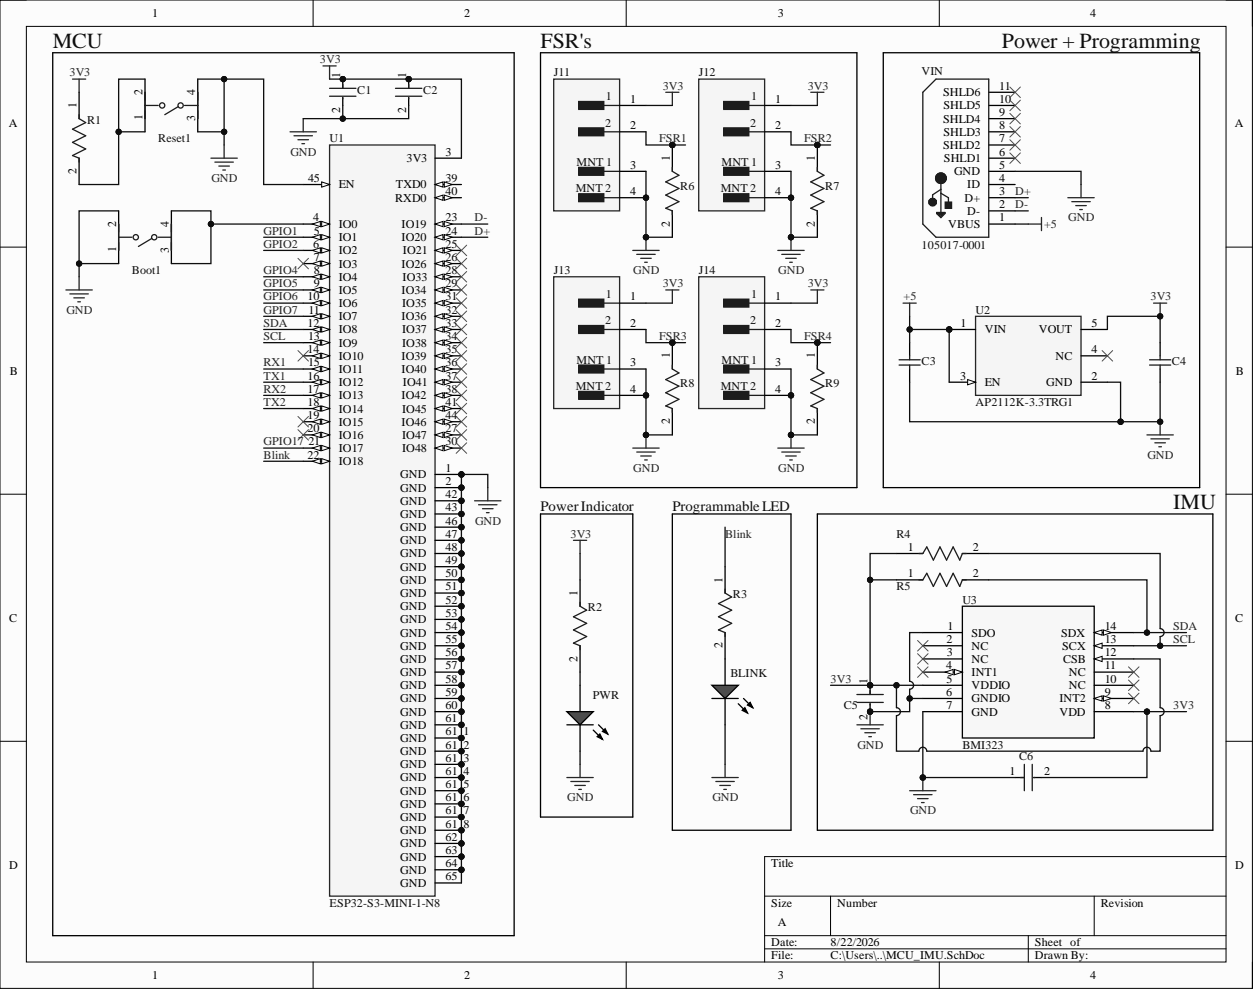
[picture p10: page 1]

4 2

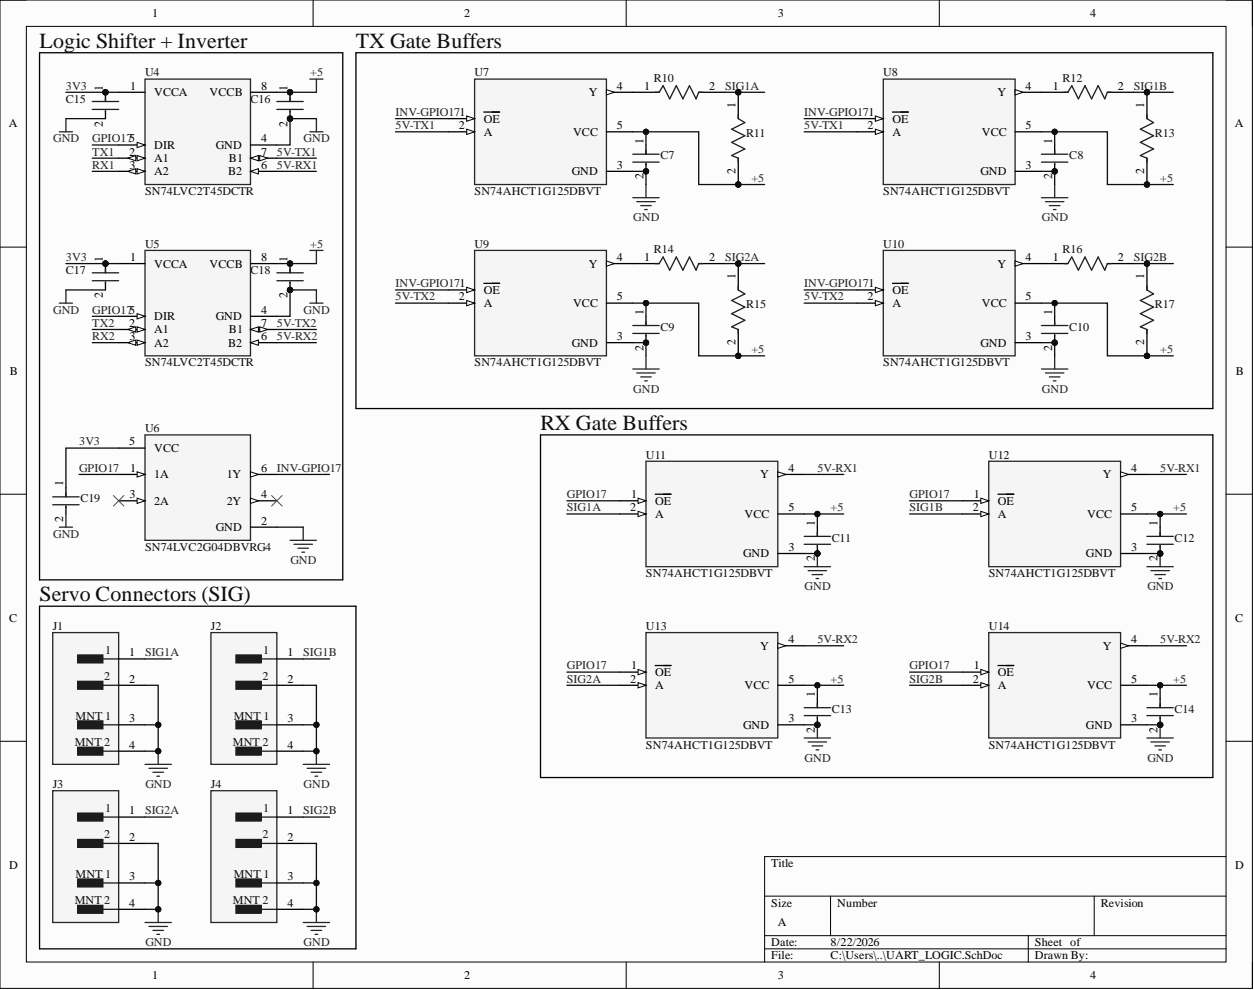
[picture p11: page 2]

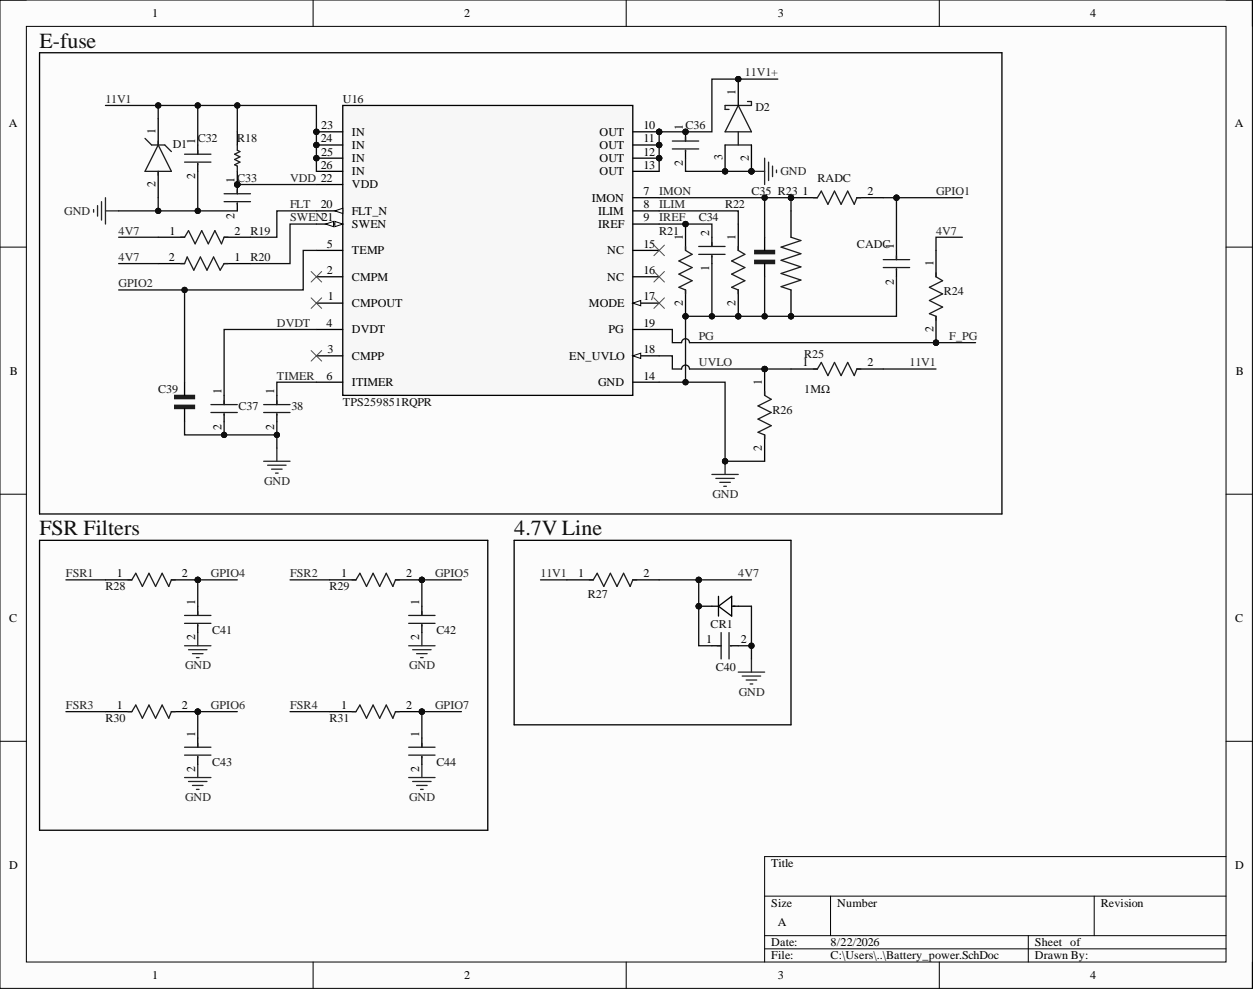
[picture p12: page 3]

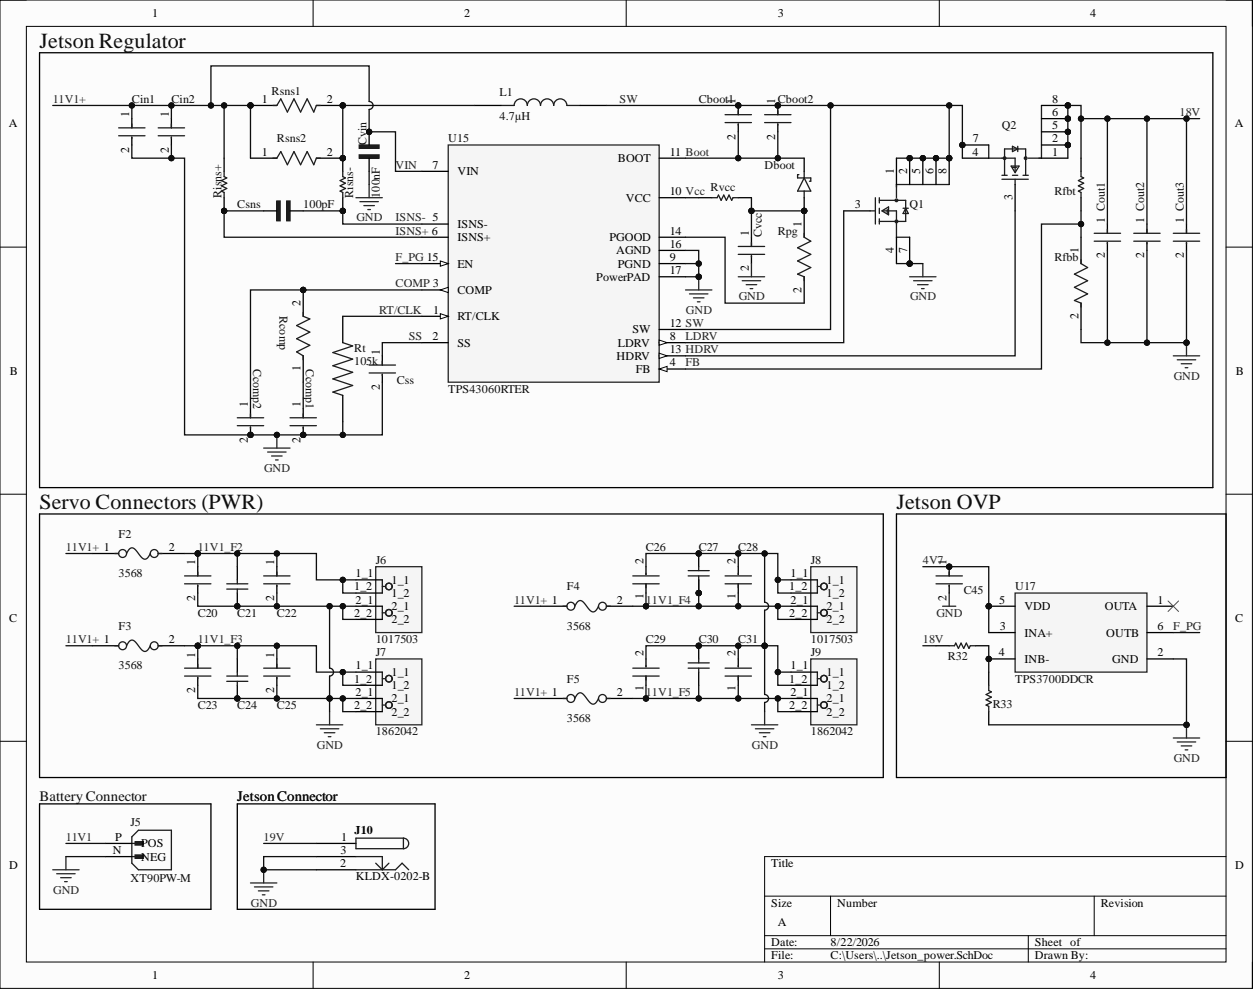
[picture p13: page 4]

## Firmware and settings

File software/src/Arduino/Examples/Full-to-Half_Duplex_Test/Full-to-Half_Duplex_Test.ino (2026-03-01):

#include <SCServo.h>

SMS_STS sms_sts;


int dirGPIO = 4;

void setup()
{
  pinMode(dirGPIO,OUTPUT);
  digitalWrite(dirGPIO, LOW); // Start in Receive mode
  Serial.begin(115200);
  Serial1.begin(1000000, SERIAL_8N1, 11, 12);
  delay(1000);
}

void loop()
{
  digitalWrite(dirGPIO, HIGH); // Switch to Transmit
  Serial.println("Transmitting Mode Activated");
  delay(5000);
  digitalWrite(dirGPIO, LOW); // Switch  Receive mode
  Serial.println("Receiving Mode Activated");
  delay(5000);
}

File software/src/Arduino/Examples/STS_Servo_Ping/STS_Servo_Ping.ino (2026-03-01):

#include <SCServo.h>

SMS_STS sms_sts;

int LEDpin = 8;
int dirGPIO = 4;

void setup()
{
  pinMode(LEDpin,OUTPUT);
  pinMode(dirGPIO,OUTPUT);
  digitalWrite(dirGPIO, LOW); // Start in Receive mode
  digitalWrite(LEDpin, HIGH);
  Serial.begin(115200);
  Serial1.begin(1000000, SERIAL_8N1, 11, 12, false);
  sms_sts.pSerial = &Serial1;
  delay(1000);
}


void loop()
{

  digitalWrite(dirGPIO, HIGH); // Switch to Transmit

  delay(500);


  sms_sts.WritePosEx(1, 2048, 1000, 50);
  delay(5000);
  sms_sts.WritePosEx(1, 0, 2400, 50);
  //int ID = sms_sts.Ping(1);

  Serial1.flush();
  digitalWrite(dirGPIO, LOW); // Switch  Receive mode

  /*
  if(ID != -1 && !sms_sts.getLastError()){
    digitalWrite(LEDpin, HIGH);
    Serial.print("Servo ID:");
    Serial.println(ID, DEC);
    delay(100);
  }else{
    int err = sms_sts.getLastError();
    if(err == 0) {
       Serial.println("TIMEOUT: No servo with ID 1 found. Is it powered?");
    } else {
       Serial.print("COMM ERROR: Data was corrupted. Error code: ");
       Serial.println(err);
    }
    digitalWrite(LEDpin, LOW);
    delay(2000);
  }
  */
  delay(2000);
}

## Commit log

2025-04-10 Initialize New Repository w/ Current Files
    [Arm.SLDPRT, ForeArm.SLDPRT, Hip.SLDPRT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]
2025-04-11 Mark3 Daily Update
    [DS5160ssg_60KG_Servo.SLDPRT, M2 x 0.4mm Thread 12mm LONG SOCKET HEAD CAP SCREW.SLDPRT, Torso_Casing.SLDPRT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]
2025-04-11 Mark3 Daily Update Fix
    [DS3240_Servomotor 40Kg.SLDPRT, DS5160ssg_60KG_Servo.SLDPRT, M3x12mm.SLDPRT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]
2025-04-11 Fixed Update
    [DS3240_Servomotor 40Kg.SLDPRT, DS5160ssg_60KG_Servo.SLDPRT, Elbow.SLDPRT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]
2025-04-18 Started leg CAD
    [DS3218MG MS24 Digital Servo 270.SLDPRT, Hip.SLDPRT, Hip_Connector.SLDPRT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]
2025-04-19 further leg progression
    [DS3218MG MS24 Digital Servo 270.SLDPRT, Hip_Connector.SLDPRT, Knee.SLDPRT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]
2025-05-06 Updated battery and power sheet
    [Power_Excel.xlsx]
2025-05-07 changed to new battery
    [Battery_Mounter.SLDPRT, Casing.SLDPRT, Hip.SLDPRT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]
2026-01-02 Revise Bill of Materials with updated parts and costs
    Updated the Bill of Materials with new parts and adjusted descriptions. Revised pricing and subtotals for mechanical, electrical, and computing sections.
2026-01-02 Clarify description of DC Power Cable
    Updated the description of the Male to Male DC Power Cable for clarity.
2026-01-04 added exports and updated CAD's
    [1mm-dowel.SLDPRT, 1mm-dowel.STEP, 2mm-dowel.SLDPRT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]
2026-01-04 added pdf of PCB schematics
2026-03-01 ERGOS Update - 3/1/2026
    [12mm Bearing.SLDPRT, 1mm-dowel.STEP, 2mm-dowel.STEP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]
2026-03-01 Removed clutter files and added gitignore
    [ROBOT_MOTHERBOARD.GBL, ROBOT_MOTHERBOARD.GBO, ROBOT_MOTHERBOARD.GBP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]
2026-03-01 Upload mechanical updates
    [8mm-aluminum-shaft3.SLDPRT, Ankle-Assembly-Right-V2.SLDASM, Ankle-pulley-plate.SLDPRT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]
2026-03-01 Switch to Git LFS for CAD
    [12mm Bearing.SLDPRT, 1mm-dowel.SLDPRT, 2mm-dowel.SLDPRT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]
2026-04-12 Update CAD & Docs
    [Ankle-Assembly-Right-V2.SLDASM, Ankle-housing-left-v2.SLDPRT, Ankle-housing-left-v2.STEP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]
2026-04-27 Update CAD
    [Ankle-housing-left-v2.SLDPRT, Ankle-pulley-plate.SLDPRT, Ankle-pulley-plate.STEP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]
2026-05-09 ERGOS-5/9/2025 Clean Mechanical Folder V1
    [12mm Bearing.SLDPRT, 1mm-dowel.SLDPRT, 2mm-dowel.SLDPRT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]
2026-08-22 Update Electrical
    [4040x600mm.SLDPRT, Battery_power.SchDoc, Caster_Wheel.SLDPRT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]
2026-09-07 Revamp docs and sync hardware snapshot
    [Battery_power.SchDoc, Chassis_Assembly.SLDASM, Final_Robot_Assembly.SLDASM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]
